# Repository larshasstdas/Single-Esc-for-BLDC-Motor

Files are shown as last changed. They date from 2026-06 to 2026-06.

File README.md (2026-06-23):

# Single ESC for BLDC Motor

A custom single-channel ESC (Electronic Speed Controller) for BLDC motors. I want to programm and test the esc before modifying it into a 4in1 esc i can use for flying a drone.

## Overview

This repository contains the KiCad schematic and PCB layout for a single-channel ESC. The design is based on the DRV8353 gate driver and BSC010N04LSI MOSFETs, controlled by an STM32G431 microcontroller. It includes a buck converter for onboard power regulation, MOSFET-based battery backflow protection, and BEMF sensing for sensorless motor control.

## Files
```
├── KiCad_Files/              # KiCad design source
│   ├── SingleEsc.kicad_pro   # KiCad project file
│   ├── SingleEsc.kicad_sch   # Schematic
│   ├── SingleEsc.kicad_pcb   # PCB layout
│   ├── SingleEsc-job.gbrjob  # Gerber job file
│   ├── SingleEsc-all-pos.csv # Component placement export
│   ├── footprints/           # Custom footprint library
│   ├── myBibs/               # Custom schematic symbol library
│   └── fp-lib-table          # Footprint library table
│
├── Gerber&BOM/               # Manufacturing data
│   ├── GerberESC/            # Gerber and drill files
│   ├── DigiKey_ESC_BOM.csv   # Bill of materials (CSV)
│   ├── DigiKey_ESC_BOM.xlsx  # Bill of materials (Excel)
│   ├── ESC_PickAndPlace.csv  # Pick & place (CSV)
│   └── ESC_PickAndPlace.xlsx # Pick & place (Excel)
│
├── Gerber&BOM.zip            # Zipped Gerber, BOM and Pick & Place files
└── README.md
```
## Bill of Materials

A BOM with all components for buying on Digikey is available in the project files. Some parts need to be bought elsewhere for example the XT60 connector.

## AI Usage

AI was used for helping with a basic idea for a layout, learning about components and an idea of where to buy parts.

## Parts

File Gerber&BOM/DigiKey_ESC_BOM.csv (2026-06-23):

Country of Origin may be different at time of shipment.
The HTSUS and ECCN information shown is for informational purposes only and is not a representation or warranty as to the accuracy or reliability of these classifications. All information is provided "as is" and is subject to change without notice. Any use made of the information provided is without recourse to Digi-Key and at the user's risk.
Index | Manufacturer Part Number | Manufacturer Name | Description | Lead Time | Availability | Stock Status | Attrition % | Requested Quantity 1 | Pack Quantity 1 | Pack Type 1 | Digi-Key Part Number 1 | Unit Price 1 | Extended Price 1 | Minimum Order Quantity 1 | Customer Reference | Requested Part Number | Lead Weeks | Datasheet | Reference Designator | US Import Tariff | Note | Part Status | RoHS Status | REACH Status | Moisture Sensitivity Level (MSL) | ECCN | HTSUS | Country of Origin | Environmental Information | Original Part numbers | Unit of Measure | Image | Product Notes
1 | BSC014N06NSATMA1 | Infineon Technologies | MOSFET N-CH 60V 30A/100A TDSON7 |  | 67.842 | In Stock |  | 10 | 10 | Cut Tape (CT) | BSC014N06NSATMA1CT-ND | 3,10300 | €31.03 | 1 |  | BSC014N06NSATMA1CT-ND | 61 | https://www.infineon.com/dgdl/BSC014N06NS_Rev2.0.pdf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 |  | N/A |  | Active | ROHS3 Compliant | REACH Unaffected | 1 (Unlimited) | EAR99 | 8541.29.0055 | Germany | https://www.cypress.com/file/199231/download | BSC014N06NSATMA1CT-ND | Each | https://mm.digikey.com/Volume0/opasdata/d220001/medias/images/2460/448%3B-P%5EPG-TDSON-8-17%3B-%3B-8-Top-View.jpg
2 | RC0603FR-0710RL | YAGEO | RES 10 OHM 1% 1/10W 0603 |  | 1.195.834 | In Stock |  | 10 | 10 | Cut Tape (CT) | 311-10.0HRCT-ND | 0,03200 | €0.32 | 1 |  | 311-10.0HRCT-ND | 17 | https://yageogroup.com/content/datasheet/asset/file/PYU-RC_GROUP_51_ROHS_L |  | N/A |  | Active | ROHS3 Compliant | REACH Unaffected | 1 (Unlimited) | EAR99 | 8533.21.0030 | Taiwan | https://www.yageogroup.com/content/Resource%20Library/Product%20Environmental%20Compliance/RoHS_Compliance_YAGEO.pdf | 311-10.0HRCT-ND | Each | https://mm.digikey.com/Volume0/opasdata/d220001/derivates/6/003/121/213/cut-tape-render_web%28640x640%29.jpg
3 | RC0603FR-07100RL | YAGEO | RES 100 OHM 1% 1/10W 0603 |  | 1.700.034 | In Stock |  | 10 | 10 | Cut Tape (CT) | 311-100HRCT-ND | 0,02100 | €0.21 | 1 |  | 311-100HRCT-ND | 17 | https://yageogroup.com/content/datasheet/asset/file/PYU-RC_GROUP_51_ROHS_L |  | N/A |  | Active | ROHS3 Compliant | REACH Unaffected | 1 (Unlimited) | EAR99 | 8533.21.0030 | Taiwan | https://www.yageogroup.com/content/Resource%20Library/Product%20Environmental%20Compliance/RoHS_Compliance_YAGEO.pdf | 311-100HRCT-ND | Each | https://mm.digikey.com/Volume0/opasdata/d220001/derivates/6/003/121/213/cut-tape-render_web%28640x640%29.jpg
4 | RC0603FR-071KL | YAGEO | RES 1K OHM 1% 1/10W 0603 |  | 2.422.426 | In Stock |  | 10 | 10 | Cut Tape (CT) | 311-1.00KHRCT-ND | 0,02100 | €0.21 | 1 |  | 311-1.00KHRCT-ND | 17 | https://yageogroup.com/content/datasheet/asset/file/PYU-RC_GROUP_51_ROHS_L |  | N/A |  | Active | ROHS3 Compliant | REACH Unaffected | 1 (Unlimited) | EAR99 | 8533.21.0030 | Taiwan | https://www.yageogroup.com/content/Resource%20Library/Product%20Environmental%20Compliance/RoHS_Compliance_YAGEO.pdf | 311-1.00KHRCT-ND | Each | https://mm.digikey.com/Volume0/opasdata/d220001/derivates/6/003/121/213/cut-tape-render_web%28640x640%29.jpg
5 | RC0603FR-076K8L | YAGEO | RES 6.8K OHM 1% 1/10W 0603 |  | 135.277 | In Stock |  | 10 | 10 | Cut Tape (CT) | 311-6.80KHRCT-ND | 0,02100 | €0.21 | 1 |  | 311-6.80KHRCT-ND | 17 | https://yageogroup.com/content/datasheet/asset/file/PYU-RC_GROUP_51_ROHS_L |  | N/A |  | Active | ROHS3 Compliant | REACH Unaffected | 1 (Unlimited) | EAR99 | 8533.21.0030 | Taiwan | https://www.yageogroup.com/content/Resource%20Library/Product%20Environmental%20Compliance/RoHS_Compliance_YAGEO.pdf | 311-6.80KHRCT-ND | Each | https://mm.digikey.com/Volume0/opasdata/d220001/derivates/6/003/121/213/cut-tape-render_web%28640x640%29.jpg
6 | RC0603FR-0710KL | YAGEO | RES 10K OHM 1% 1/10W 0603 |  | 12.269.132 | In Stock |  | 25 | 25 | Cut Tape (CT) | 311-10.0KHRCT-ND | 0,01600 | €0.40 | 1 |  | 311-10.0KHRCT-ND | 17 | https://yageogroup.com/content/datasheet/asset/file/PYU-RC_GROUP_51_ROHS_L |  | N/A |  | Active | ROHS3 Compliant | REACH Unaffected | 1 (Unlimited) | EAR99 | 8533.21.0030 | Taiwan | https://www.yageogroup.com/content/Resource%20Library/Product%20Environmental%20Compliance/RoHS_Compliance_YAGEO.pdf | 311-10.0KHRCT-ND | Each | https://mm.digikey.com/Volume0/opasdata/d220001/derivates/6/003/121/213/cut-tape-render_web%28640x640%29.jpg
7 | RC0603FR-0739KL | YAGEO | RES 39K OHM 1% 1/10W 0603 |  | 199.716 | In Stock |  | 10 | 10 | Cut Tape (CT) | 311-39.0KHRCT-ND | 0,02100 | €0.21 | 1 |  | 311-39.0KHRCT-ND | 17 | https://yageogroup.com/content/datasheet/asset/file/PYU-RC_GROUP_51_ROHS_L |  | N/A |  | Active | ROHS3 Compliant | REACH Unaffected | 1 (Unlimited) | EAR99 | 8533.21.0030 | Taiwan | https://www.yageogroup.com/content/Resource%20Library/Product%20Environmental%20Compliance/RoHS_Compliance_YAGEO.pdf | 311-39.0KHRCT-ND | Each | https://mm.digikey.com/Volume0/opasdata/d220001/derivates/6/003/121/213/cut-tape-render_web%28640x640%29.jpg
8 | RC0603FR-0743K2L | YAGEO | RES 43.2K OHM 1% 1/10W 0603 |  | 57.553 | In Stock |  | 10 | 10 | Cut Tape (CT) | 311-43.2KHRCT-ND | 0,02100 | €0.21 | 1 |  | 311-43.2KHRCT-ND | 17 | https://yageogroup.com/content/datasheet/asset/file/PYU-RC_GROUP_51_ROHS_L |  | N/A |  | Active | ROHS3 Compliant | REACH Unaffected | 1 (Unlimited) | EAR99 | 8533.21.0030 | Taiwan | https://www.yageogroup.com/content/Resource%20Library/Product%20Environmental%20Compliance/RoHS_Compliance_YAGEO.pdf | 311-43.2KHRCT-ND | Each | https://mm.digikey.com/Volume0/opasdata/d220001/derivates/6/100/962/238/13_0603-%281608-metric%29_web%28640x640%29.jpg
9 | RC0603FR-07100KL | YAGEO | RES 100K OHM 1% 1/10W 0603 |  | 4.896.093 | In Stock |  | 10 | 10 | Cut Tape (CT) | 311-100KHRCT-ND | 0,02100 | €0.21 | 1 |  | 311-100KHRCT-ND | 17 | https://yageogroup.com/content/datasheet/asset/file/PYU-RC_GROUP_51_ROHS_L |  | N/A |  | Active | ROHS3 Compliant | REACH Unaffected | 1 (Unlimited) | EAR99 | 8533.21.0030 | Taiwan | https://www.yageogroup.com/content/Resource%20Library/Product%20Environmental%20Compliance/RoHS_Compliance_YAGEO.pdf | 311-100KHRCT-ND | Each | https://mm.digikey.com/Volume0/opasdata/d220001/derivates/6/003/121/213/cut-tape-render_web%28640x640%29.jpg
10 | STM32G431CBT6 | STMicroelectronics | IC MCU 32BIT 128KB FLASH 48LQFP | 2 expected in stock on 20-Jul-2026 | 0 | Normally Stocking |  | 2 | 2 | Tray | 497-19473-ND | 5,15000 | €10.30 | 1 |  | 497-19473-ND | 30 | https://www.st.com/resource/en/datasheet/stm32g431cb.pdf |  | N/A |  | Active | ROHS3 Compliant | REACH Unaffected | 3 (168 Hours) | 3A991A2 | 8542.31.0025 | Taiwan |  | 497-19473-ND | Each | https://mm.digikey.com/Volume0/opasdata/d220001/medias/images/422/497%7E5B_ME_V2%7ET%7E48.jpg
11 | DRV8353SRTAR | Texas Instruments | DRIVER | 2 expected in stock on 07-Oct-2027 | 0 | Normally Stocking |  | 2 | 2 | Cut Tape (CT) | 296-DRV8353SRTARCT-ND | 4,52000 | €9.04 | 1 |  | 296-DRV8353SRTARCT-ND | 12 | https://www.ti.com/general/docs/suppproductinfo.tsp?distId=10 |  | N/A |  | Active | ROHS3 Compliant | REACH Unaffected | 1 (Unlimited) | EAR99 | 8542.39.0070 | China |  | 296-DRV8353SRTARCT-ND | Each | https://mm.digikey.com/Volume0/opasdata/d220001/medias/images/6222/296%7E4204422%7ERTA%7E40.jpg
12 | LMR33630ADDAR | Texas Instruments | IC REG BUCK ADJ 3A 8SOPWR |  | 3.752 | In Stock |  | 1 | 1 | Cut Tape (CT) | 296-49763-1-ND | 2,45000 | €2.45 | 1 |  | 296-49763-1-ND | 6 | https://www.ti.com/general/docs/suppproductinfo.tsp?distId=10 |  | N/A |  | Active | ROHS3 Compliant | REACH Unaffected | 2 (1 Year) | EAR99 | 8542.39.0070 | Mexico |  | 296-49763-1-ND | Each | https://mm.digikey.com/Volume0/opasdata/d220001/medias/images/6284/296%7E4221637%7EDDA%7E8.jpg
13 | 74437346068 | Würth Elektronik | FIXED IND 6.8UH 3.4A 60 MOHM SMD |  | 4.040 | In Stock |  | 1 | 1 | Cut Tape (CT) | 732-3377-1-ND | 1,93000 | €1.93 | 1 |  | 732-3377-1-ND | 18 | https://www.we-online.com/components/products/datasheet/74437346068.pdf |  | N/A |  | Active | ROHS3 Compliant | REACH Unaffected | 1 (Unlimited) | EAR99 | 8504.50.4000 | China | https://mm.digikey.com/Volume0/opasdata/d220001/medias/docus/744/Certificate_of_Compliance_ROHS.pdf | 732-3377-1-ND | Each | https://mm.digikey.com/Volume0/opasdata/d220001/derivates/6/002/312/WE-LHMI-2_web%28640x640%29.jpg
14 | 61300311121 | Würth Elektronik | CONN HEADER VERT 3POS 2.54MM |  | 254.478 | In Stock |  | 1 | 1 | Bag | 732-5316-ND | 0,11000 | €0.11 | 1 |  | 732-5316-ND | 18 | https://www.we-online.com/components/products/datasheet/61300311121.pdf |  | N/A |  | Active | ROHS3 Compliant | REACH Unaffected | Not Applicable | EAR99 | 8536.69.4040 | Taiwan | https://mm.digikey.com/Volume0/opasdata/d220001/medias/docus/744/Certificate_of_Compliance_ROHS.pdf | 732-5316-ND | Each | https://mm.digikey.com/Volume0/opasdata/d220001/medias/images/1006/61300311121.JPG
15 | FTSH-105-01-L-DV | Samtec Inc. | CONN HEADER SMD 10POS 1.27MM | Unable to be ordered | 2.661 | In Stock - Non-Stock |  | 1 | 1 | Bulk | SAM1161-05-ND | 1,38000 | €1.38 | 1 |  | SAM1161-05-ND | 2 | https://suddendocs.samtec.com/catalog_english/ftsh_smt.pdf |  | N/A |  | Discontinued at Digi-Key | ROHS3 Compliant | REACH Unaffected | 1 (Unlimited) | EAR99 | 8536.69.4040 | United States |  | SAM1161-05-ND | Each | https://mm.digikey.com/Volume0/opasdata/d220001/medias/images/2514/FTSH-1xx-0x-x-DV.jpg
16 | TLR3APSDTE3L00F50 | KOA Speer Electronics, Inc. | RES 3M OHM 1% 5W 2512 |  | 1.387 | In Stock |  | 4 | 4 | Cut Tape (CT) | 2019-TLR3APSDTE3L00F50CT-ND | 1,32000 | €5.28 | 1 |  | 2019-TLR3APSDTE3L00F50CT-ND | 10 | https://www.koaspeer.com/pdfs/TLR-2BW-2BP-2HW-3AP-3APS.pdf |  | N/A |  | Active | ROHS3 Compliant | REACH Unaffected | 1 (Unlimited) | EAR99 | 8533.21.0030 | Japan | https://www.koaglobal.com/product/common/rohs|https://mm.digikey.com/Volume0/opasdata/d220001/medias/docus/5718/2019_KOA%20Speer%20RoHS3%20Statement.pdf | 2019-TLR3APSDTE3L00F50CT-ND | Each | https://mm.digikey.com/Volume0/opasdata/d220001/medias/images/320/2019%3B%3BTLR-2512%286432%29-3mOhm.JPG
17 | C0603C102K5RACTU | KEMET | CAP CER 1000PF 50V X7R 0603 |  | 2.155.016 | In Stock |  | 10 | 10 | Cut Tape (CT) | 399-C0603C102K5RACTUCT-ND | 0,03600 | €0.36 | 1 |  | 399-C0603C102K5RACTUCT-ND | 22 | https://yageogroup.com/content/datasheet/asset/file/KEM_C1002_X7R_SMD |  | N/A |  | Active | ROHS3 Compliant | REACH Unaffected | 1 (Unlimited) | EAR99 | 8532.24.0020 | Taiwan |  | 399-C0603C102K5RACTUCT-ND | Each | https://mm.digikey.com/Volume0/opasdata/d220001/derivates/6/003/121/213/cut-tape-render_web%28640x640%29.jpg
18 | C0603C103K5RACTU | KEMET | CAP CER 10000PF 50V X7R 0603 |  | 5.541.875 | In Stock |  | 10 | 10 | Cut Tape (CT) | 399-C0603C103K5RACTUCT-ND | 0,04100 | €0.41 | 1 |  | 399-C0603C103K5RACTUCT-ND | 22 | https://yageogroup.com/content/datasheet/asset/file/KEM_C1002_X7R_SMD |  | N/A |  | Active | ROHS3 Compliant | REACH Unaffected | 1 (Unlimited) | EAR99 | 8532.24.0020 | Taiwan |  | 399-C0603C103K5RACTUCT-ND | Each | https://mm.digikey.com/Volume0/opasdata/d220001/derivates/6/003/121/213/cut-tape-render_web%28640x640%29.jpg
19 | C0603C473K5RACTU | KEMET | CAP CER 0.047UF 50V X7R 0603 |  | 494.126 | In Stock |  | 10 | 10 | Cut Tape (CT) | 399-C0603C473K5RACTUCT-ND | 0,04000 | €0.40 | 1 |  | 399-C0603C473K5RACTUCT-ND | 12 | https://yageogroup.com/content/datasheet/asset/file/KEM_C1002_X7R_SMD |  | N/A |  | Active | ROHS3 Compliant | REACH Unaffected | 1 (Unlimited) | EAR99 | 8532.24.0020 | China |  | 399-C0603C473K5RACTUCT-ND | Each | https://mm.digikey.com/Volume0/opasdata/d220001/derivates/6/003/121/213/cut-tape-render_web%28640x640%29.jpg
20 | C0603C104K5RACTU | KEMET | CAP CER 0.1UF 50V X7R 0603 |  | 8.437.259 | In Stock |  | 10 | 10 | Cut Tape (CT) | 399-C0603C104K5RACTUCT-ND | 0,04700 | €0.47 | 1 |  | 399-C0603C104K5RACTUCT-ND | 12 | https://yageogroup.com/content/datasheet/asset/file/KEM_C1002_X7R_SMD |  | N/A |  | Active | ROHS3 Compliant | REACH Unaffected | 1 (Unlimited) | EAR99 | 8532.24.0020 | China |  | 399-C0603C104K5RACTUCT-ND | Each | https://mm.digikey.com/Volume0/opasdata/d220001/derivates/6/003/121/213/cut-tape-render_web%28640x640%29.jpg
21 | CC0603KRX7R9BB224 | YAGEO | CAP CER 0.22UF 50V X7R 0603 |  | 2.684 | In Stock |  | 10 | 10 | Cut Tape (CT) | 311-3374-1-ND | 0,13700 | €1.37 | 1 |  | 311-3374-1-ND | 20 | https://yageogroup.com/content/datasheet/asset/file/UPY-GPHC_X7R_6_3V-TO-250V |  | N/A |  | Active | ROHS3 Compliant | REACH Unaffected | 1 (Unlimited) | EAR99 | 8532.24.0020 | Taiwan |  | 311-3374-1-ND | Each | https://mm.digikey.com/Volume0/opasdata/d220001/medias/images/2488/0603%289mmthickness%29.jpg
22 | C0603C105K4RACTU | KEMET | CAP CER 1UF 16V X7R 0603 |  | 4.644.752 | In Stock |  | 10 | 10 | Cut Tape (CT) | 399-C0603C105K4RACTUCT-ND | 0,04600 | €0.46 | 1 |  | 399-C0603C105K4RACTUCT-ND | 38 | https://yageogroup.com/content/datasheet/asset/file/KEM_C1002_X7R_SMD |  | N/A |  | Active | ROHS3 Compliant | REACH Unaffected | 1 (Unlimited) | EAR99 | 8532.24.0020 | Taiwan |  | 399-C0603C105K4RACTUCT-ND | Each | https://mm.digikey.com/Volume0/opasdata/d220001/derivates/6/003/121/213/cut-tape-render_web%28640x640%29.jpg
23 | GCM188R71E105KA64J | Murata Electronics | CAP CER 1UF 25V X7R 0603 |  | 142.747 | In Stock |  | 10 | 10 | Cut Tape (CT) | 490-GCM188R71E105KA64JCT-ND | 0,08500 | €0.85 | 1 |  | 490-GCM188R71E105KA64JCT-ND | 21 | https://search.murata.co.jp/Ceramy/image/img/A01X/G101/ENG/GCM188R71E105KA64-04A.pdf |  | N/A |  | Active | ROHS3 Compliant | REACH Unaffected | 1 (Unlimited) | EAR99 | 8532.24.0020 | Philippines |  | 490-GCM188R71E105KA64JCT-ND | Each | https://mm.digikey.com/Volume0/opasdata/d220001/medias/images/5447/490-Ceramic-Capacitor-Tan-Field.jpg
24 | GCM31CR71E475KA55L | Murata Electronics | CAP CER 4.7UF 25V X7R 1206 |  | 210.874 | In Stock |  | 2 | 2 | Cut Tape (CT) | 490-4794-1-ND | 0,27000 | €0.54 | 1 |  | 490-4794-1-ND | 21 | https://search.murata.co.jp/Ceramy/image/img/A01X/G101/ENG/GCM31CR71E475KA55-01A.pdf |  | N/A |  | Active | ROHS3 Compliant | REACH Unaffected | 1 (Unlimited) | EAR99 | 8532.24.0020 | Philippines |  | 490-4794-1-ND | Each | https://mm.digikey.com/Volume0/opasdata/d220001/medias/images/5447/490-Ceramic-Capacitor-Tan-Field.jpg
25 | C3225X7R1E106K250AC | TDK | CAP CER 10UF 25V X7R 1210 |  | 107.110 | In Stock |  | 2 | 2 | Cut Tape (CT) | 445-3942-1-ND | 0,52000 | €1.04 | 1 |  | 445-3942-1-ND | 12 | https://product.tdk.com/system/files/dam/doc/product/capacitor/ceramic/mlcc/catalog/mlcc_commercial_general_en.pdf |  | N/A |  | Active | ROHS3 Compliant | REACH Unaffected | 1 (Unlimited) | EAR99 | 8532.24.0020 | Japan | https://product.tdk.com/system/files/dam/doc/product/capacitor/ceramic/mlcc/rohs/mlccrohs_commercial_general_en.pdf|https://product.tdk.com/en/environment/index.html | 445-3942-1-ND | Each | https://mm.digikey.com/Volume0/opasdata/d220001/medias/images/4848/445_1210-%283225-Metric%29-2%2C80mm-C-Series.jpg
26 | C3225X7R1H106K250AC | TDK | COMMERCIAL GRADE GENERAL PURPOSE |  | 63.842 | In Stock |  | 2 | 2 | Cut Tape (CT) | 445-C3225X7R1H106K250ACCT-ND | 0,83000 | €1.66 | 1 |  | 445-C3225X7R1H106K250ACCT-ND | 12 | https://product.tdk.com/system/files/dam/doc/product/capacitor/ceramic/mlcc/catalog/mlcc_commercial_general_en.pdf |  | N/A |  | Active | ROHS3 Compliant | REACH Unaffected | 1 (Unlimited) | EAR99 | 8532.24.0020 | Japan | https://product.tdk.com/system/files/dam/doc/product/capacitor/ceramic/mlcc/rohs/mlccrohs_commercial_general_en.pdf|https://product.tdk.com/en/environment/index.html | 445-C3225X7R1H106K250ACCT-ND | Each | https://mm.digikey.com/Volume0/opasdata/d220001/medias/images/4848/445_1210-%283225-Metric%29-2%2C80mm-C-Series.jpg
27 | C3225X7R1C226K250AC | TDK | CAP CER 22UF 16V X7R 1210 |  | 162.288 | In Stock |  | 5 | 5 | Cut Tape (CT) | 445-3945-1-ND | 0,65000 | €3.25 | 1 |  | 445-3945-1-ND | 24 | https://product.tdk.com/system/files/dam/doc/product/capacitor/ceramic/mlcc/catalog/mlcc_commercial_general_en.pdf |  | N/A |  | Not For New Designs | ROHS3 Compliant | REACH Unaffected | 1 (Unlimited) | EAR99 | 8532.24.0020 | Japan | https://product.tdk.com/system/files/dam/doc/product/capacitor/ceramic/mlcc/rohs/mlccrohs_commercial_general_en.pdf|https://product.tdk.com/en/environment/index.html | 445-3945-1-ND | Each | https://mm.digikey.com/Volume0/opasdata/d220001/medias/images/4848/445_1210-%283225-Metric%29-2%2C80mm-C-Series.jpg
28 | GYG1V471MCW1GS | Nichicon | 35V 470F HYBRID POLYMER CHIP CHI |  | 875 | In Stock |  | 3 | 3 | Cut Tape (CT) | 493-GYG1V471MCW1GSCT-ND | 2,01000 | €6.03 | 1 |  | 493-GYG1V471MCW1GSCT-ND | 25 | https://www.nichicon.com/getmedia/794506d5-b0a7-4431-90fa-9a3c61397cd1/e-gyg_1.pdf |  | N/A |  | Active | ROHS3 Compliant | REACH Unaffected | 1 (Unlimited) | EAR99 | 8532.22.0020 | Japan |  | 493-GYG1V471MCW1GSCT-ND | Each | https://mm.digikey.com/Volume0/opasdata/d220001/derivates/6/003/235/317/MFG_2610_20SERIES_web%28640x640%29.jpg
29 | SZMMSZ5245BT1G | onsemi | DIODE ZENER 15V 500MW SOD123 |  | 2.927 | In Stock |  | 2 | 2 | Cut Tape (CT) | SZMMSZ5245BT1GOSCT-ND | 0,29000 | €0.58 | 1 |  | SZMMSZ5245BT1GOSCT-ND | 45 | https://www.onsemi.com/pdf/datasheet/mmsz5221bt1-d.pdf |  | N/A |  | Active | ROHS3 Compliant | REACH Unaffected | 1 (Unlimited) | EAR99 | 8541.10.0050 | China | https://www.onsemi.com/site/pdf/RoHS-statement.pdf|https://www.onsemi.com/site/pdf/onsemi-REACH-Statement.pdf|https://www.onsemi.com/PowerSolutions/MaterialComposition.do?export=pdf&opnId=SZMMSZ5245BT1G | SZMMSZ5245BT1GOSCT-ND | Each | https://mm.digikey.com/Volume0/opasdata/d220001/medias/images/6241/488%7E425-04%7EZ%7E2.jpg
30 | BAT54W | Diotec Semiconductor | DIODE SCHOTTKY 30V 200MA SOT323 | 2 estimated in stock on 09-Oct-2026 | 0 | Normally Stocking |  | 2 | 2 | Cut Tape (CT) | 4878-BAT54WCT-ND | 0,16000 | €0.32 | 1 |  | 4878-BAT54WCT-ND | 10 | https://diotec.com/request/datasheet/bat54w.pdf |  | N/A |  | Active | ROHS3 Compliant | REACH Unaffected | 1 (Unlimited) | EAR99 | 8541.10.0070 | China | https://diotec.com/request/imds/p201_e.pdf | 4878-BAT54WCT-ND | Each | https://mm.digikey.com/Volume0/opasdata/d220001/derivates/6/003/224/678/4878%7ESOT323%7E%7E3_web%28640x640%29.jpg

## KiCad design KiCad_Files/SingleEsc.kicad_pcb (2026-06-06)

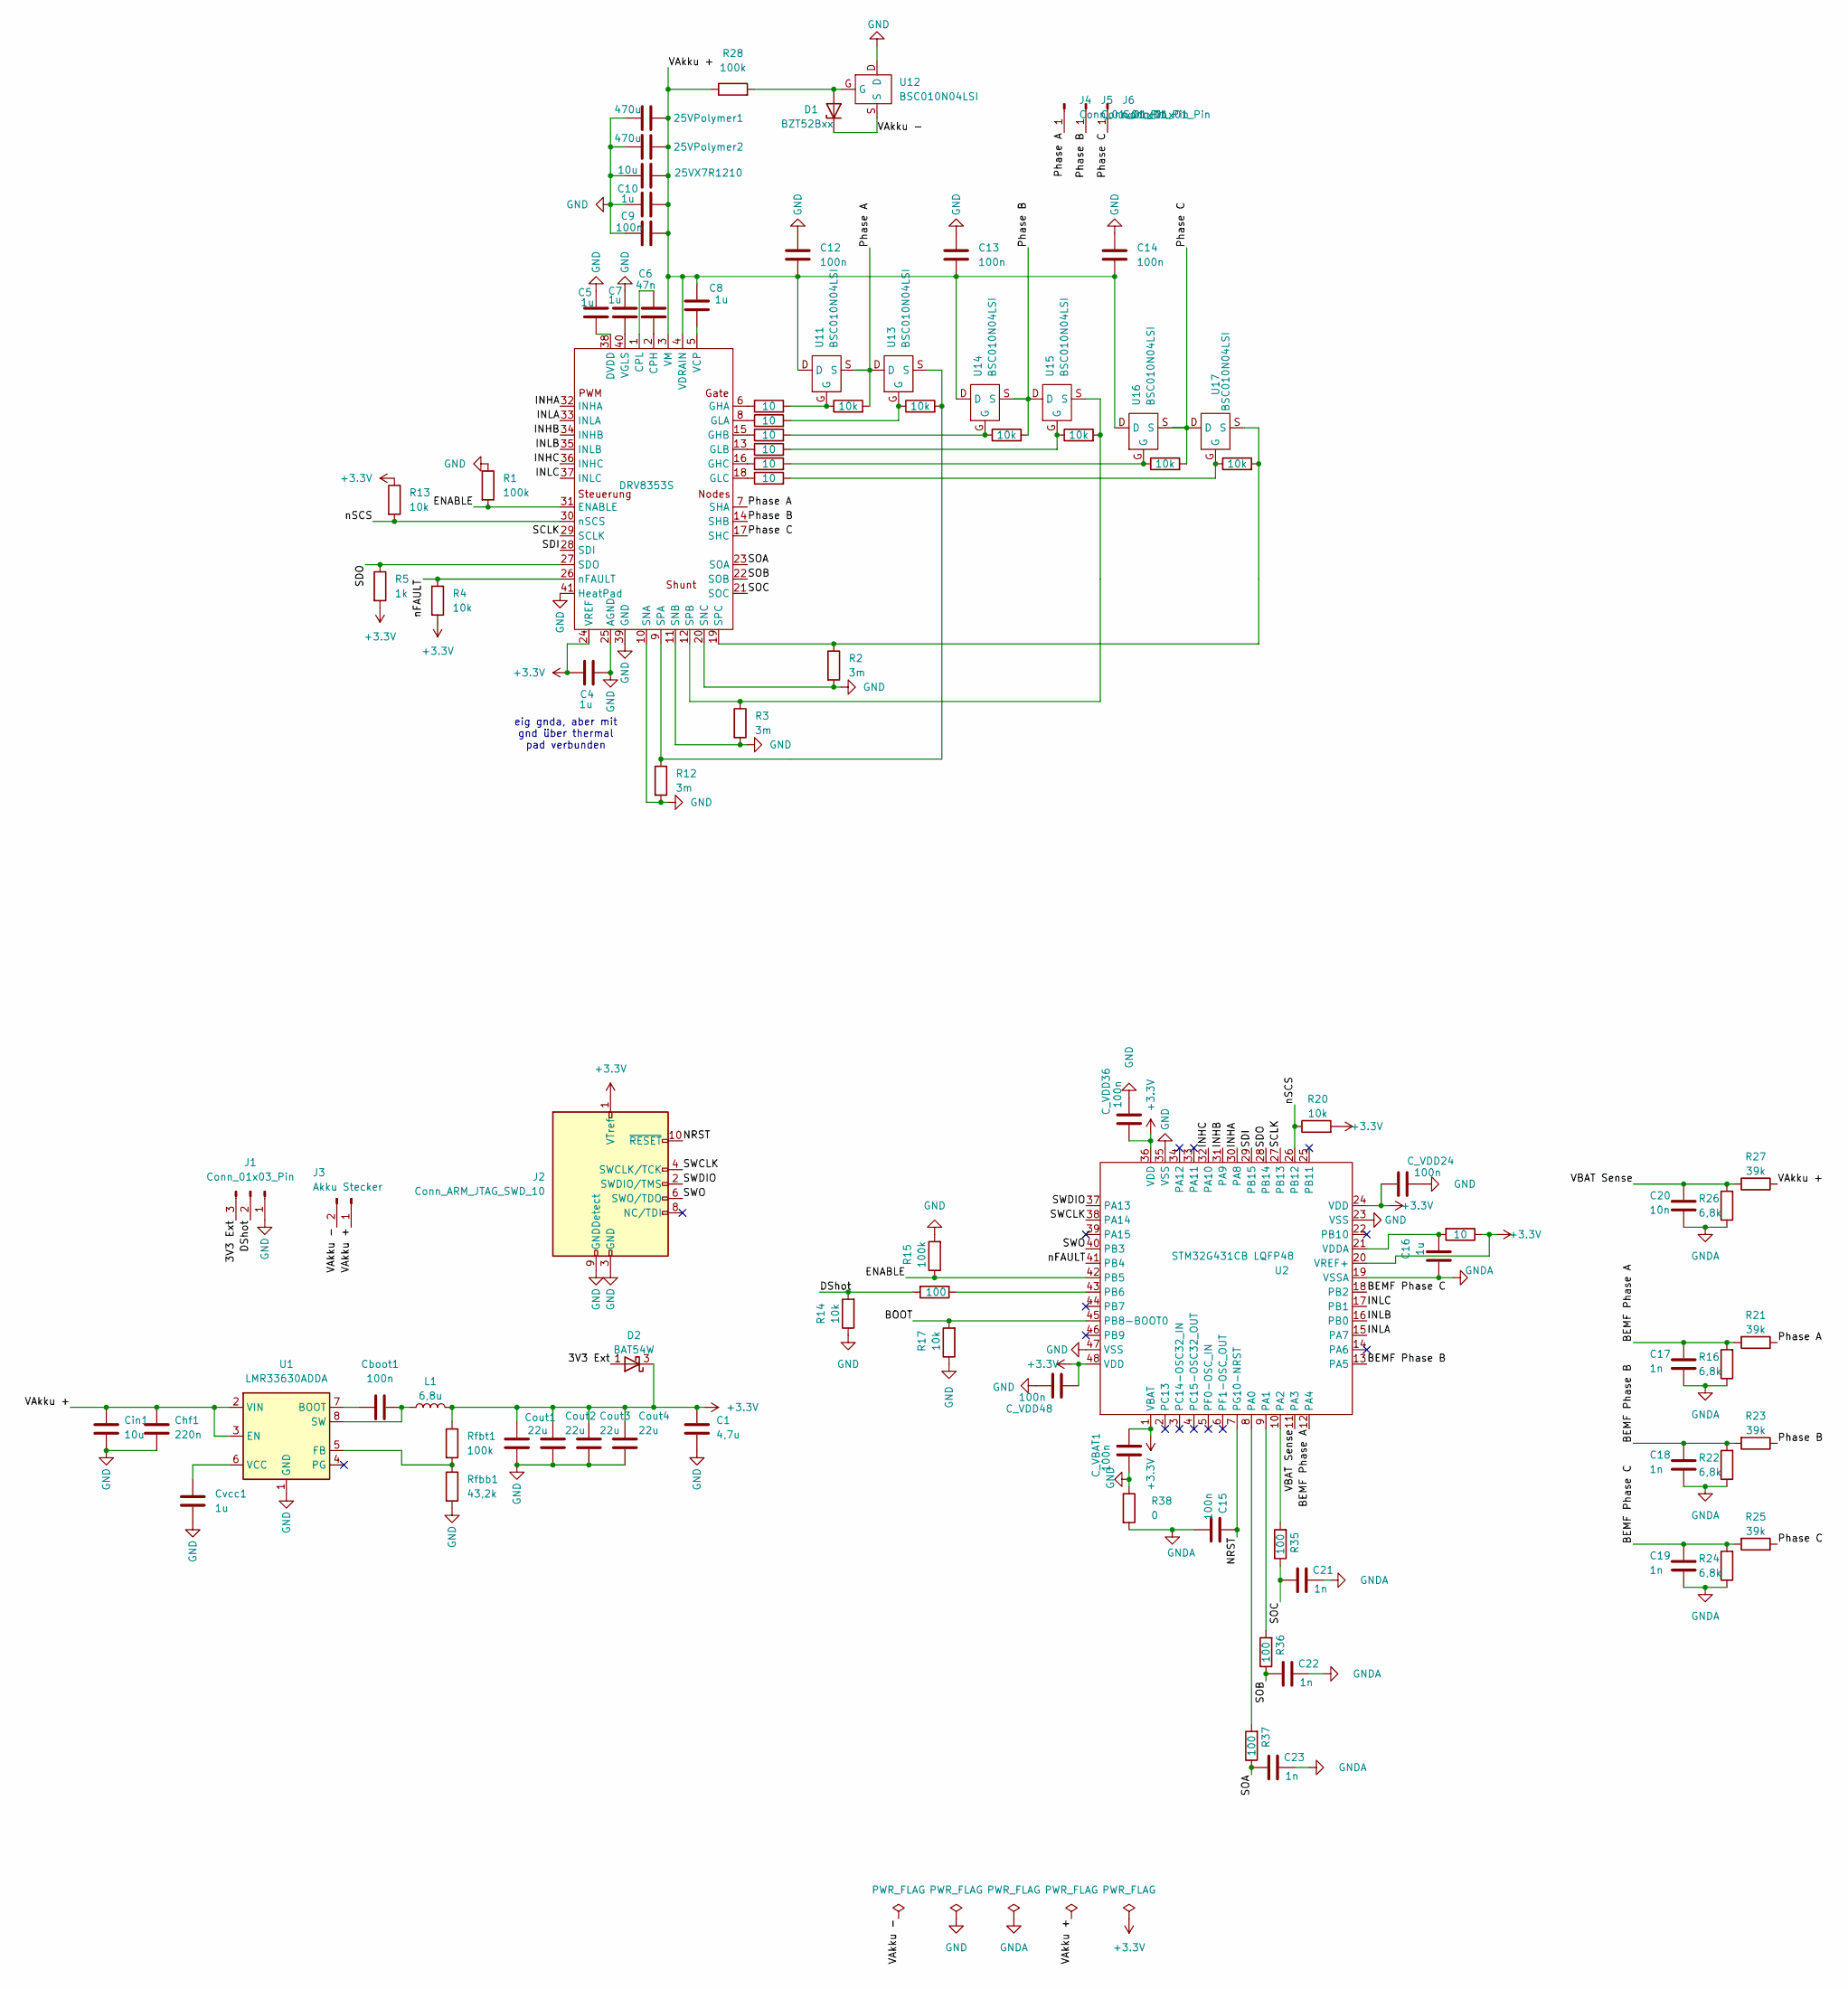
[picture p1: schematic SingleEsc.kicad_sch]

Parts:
25VPolymer1, 25VPolymer2: 470u; C_1206_3216Metric
25VX7R1210: 10u; C_0603_1608Metric
C1: 4,7u; C_0603_1608Metric
C4, C5, C7, C8, C10, C16: 1u; C_0603_1608Metric
C6: 47n; C_0603_1608Metric
C9, C15: 100n; C_0603_1608Metric
C12, C13, C14: 100n; C_0805_2012Metric
C17, C18, C19, C21, C22, C23: 1n; C_0603_1608Metric
C20: 10n; C_0603_1608Metric
C_VBAT1: 100n; C_0603_1608Metric
C_VDD24, C_VDD36, C_VDD48: 100n; C_0603_1608Metric
Cboot1: 100n; C_0603_1608Metric
Chf1: 220n; C_0603_1608Metric
Cin1: 10u; C_1210_3225Metric
Cout1, Cout2, Cout3, Cout4: 22u; C_1210_3225Metric
Cvcc1: 1u; C_0603_1608Metric
D1: BZT52Bxx; D_SOD-123F
D2: BAT54W; SOT-323_SC-70
J1: Conn_01x03_Pin; PinHeader_1x03_P2.54mm_Horizontal
J2: Conn_ARM_JTAG_SWD_10; PinHeader_2x05_P1.27mm_Vertical_SMD
J3: Akku Stecker; AMASS_XT60PW-M_1x02_P7.20mm_Horizontal
J4, J5, J6: Conn_01x01_Pin; SolderWirePad_1x01_SMD_5x10mm
L1: 6,8u; L_Wurth_WE-LHMI-7030
R1: 100k; C_0603_1608Metric
R2, R3, R12: 3m; R_2512_6332Metric
R4, R13: 10k; C_0603_1608Metric
R5: 1k; C_0603_1608Metric
R6, R7, R8, R9, R10, R11, R18: 10; R_0805_2012Metric
R14, R17, R20, R29, R30, R31, R32, R33, R34: 10k; R_0603_1608Metric
R15, R28: 100k; R_0603_1608Metric
R16, R22, R24, R26: 6,8k; R_0603_1608Metric
R19, R35, R36, R37: 100; R_0603_1608Metric
R21, R23, R25, R27: 39k; R_0603_1608Metric
R38: 0; R_0603_1608Metric
Rfbb1: 43,2k; C_0603_1608Metric
Rfbt1: 100k; C_0603_1608Metric
U1: LMR33630ADDA; Texas_HSOP-8-1EP_3.9x4.9mm_P1.27mm_ThermalVias
U2: STM32G431CB LQFP48
U11, U12, U13, U14, U15, U16, U17: BSC010N04LSI
U18: DRV8353S

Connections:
+3.3V: C1.1, C4.1, C_VBAT1.1, C_VDD24.1, C_VDD36.1, C_VDD48.1, Cout1.1, Cout2.1, Cout3.1, Cout4.1, D2.3 (K), J2.1 (VTref), L1.1, R4.2, R5.2, R13.1, R18.1, R20.2, Rfbt1.1, U2.1 (VBAT), U2.20 (VREF+), U2.24 (VDD), U2.36 (VDD), U2.48 (VDD), U18.24 (VREF)
/3V3 Ext: D2.1 (A), J1.3
/BEMF Phase A: C17.1, R16.2, R21.2, U2.12 (PA4)
/BEMF Phase B: C18.1, R22.2, R23.2, U2.13 (PA5)
/BEMF Phase C: C19.1, R24.2, R25.2, U2.18 (PB2)
/BOOT: R17.2, U2.45 (PB8-BOOT0)
/DShot: J1.2, R14.2, R19.2
/ENABLE: R1.2, R15.1, U2.42 (PB5), U18.31 (ENABLE)
/INHA: U2.30 (PA8), U18.32 (INHA)
/INHB: U2.31 (PA9), U18.34 (INHB)
/INHC: U2.32 (PA10), U18.36 (INHC)
/INLA: U2.15 (PA7), U18.33 (INLA)
/INLB: U2.16 (PB0), U18.35 (INLB)
/INLC: U2.17 (PB1), U18.37 (INLC)
/NRST: C15.1, J2.10 (~RESET), U2.7 (PG10-NRST)
/Phase A: J4.1 (Pin_1_1), R21.1, R29.2, U11.S, U13.D, U18.7 (SHA)
/Phase B: J5.1 (Pin_1_1), R23.1, R31.2, U14.S, U15.D, U18.14 (SHB)
/Phase C: J6.1 (Pin_1_1), R25.1, R33.2, U16.S, U17.D, U18.17 (SHC)
/SCLK: U2.27 (PB13), U18.29 (SCLK)
/SDI: U2.29 (PB15), U18.28 (SDI)
/SDO: R5.1, U2.28 (PB14), U18.27 (SDO)
/SOA: C23.2, R37.1, U18.23 (SOA)
/SOB: C22.2, R36.1, U18.22 (SOB)
/SOC: C21.2, R35.1, U18.21 (SOC)
/SWCLK: J2.4 (SWCLK/TCK), U2.38 (PA14)
/SWDIO: J2.2 (SWDIO/TMS), U2.37 (PA13)
/SWO: J2.6 (SWO/TDO), U2.40 (PB3)
/VAkku +: 25VPolymer1.2, 25VPolymer2.2, 25VX7R1210.2, C8.1, C9.2, C10.2, C12.1, C13.1, C14.1, Chf1.1, Cin1.1, J3.1, R27.1, R28.1, U1.2 (VIN), U1.3 (EN), U11.D, U14.D, U16.D, U18.3 (VM), U18.4 (VDRAIN)
/VAkku -: D1.1 (K), J3.2, U12.S
/VBAT Sense: C20.1, R26.2, R27.2, U2.11 (PA3)
/nFAULT: R4.1, U2.41 (PB4), U18.26 (nFAULT)
/nSCS: R13.2, R20.1, U2.26 (PB12), U18.30 (nSCS)
GND: 25VPolymer1.1, 25VPolymer2.1, 25VX7R1210.1, C1.2, C4.2, C5.1, C7.1, C9.1, C10.1, C12.2, C13.2, C14.2, C_VBAT1.2, C_VDD24.2, C_VDD36.2, C_VDD48.2, Chf1.2, Cin1.2, Cout1.2, Cout2.2, Cout3.2, Cout4.2, Cvcc1.2, J1.1, J2.3 (GND), J2.5 (GND), J2.9 (GNDDetect), R1.1, R2.2, R3.2, R12.2, R14.1, R15.2, R17.1, R38.1, Rfbb1.2, U1.1 (GND), U1.9 (GND), U2.23 (VSS), U2.35 (VSS), U2.47 (VSS), U12.D, U18.10 (SNA), U18.11 (SNB), U18.20 (SNC), U18.25 (AGND), U18.39 (GND), U18.41 (HeatPad)
GNDA: C15.2, C16.1, C17.2, C18.2, C19.2, C20.2, C21.1, C22.1, C23.1, R16.1, R22.1, R24.1, R26.1, R38.2, U2.19 (VSSA)
unnamed: D1.2 (A), R28.2, U12.G
unnamed: R10.2, R33.1, U16.G
unnamed: R11.2, R34.1, U17.G
unnamed: R6.2, R29.1, U11.G
unnamed: R7.2, R30.1, U13.G
unnamed: R8.2, R31.1, U14.G
unnamed: R9.2, R32.1, U15.G
unnamed: Cboot1.1, U1.7 (BOOT)
unnamed: Rfbb1.1, Rfbt1.2, U1.5 (FB)
unnamed: Cboot1.2, L1.2, U1.8 (SW)
unnamed: Cvcc1.1, U1.6 (VCC)
unnamed: R37.2, U2.8 (PA0)
unnamed: R36.2, U2.9 (PA1)
unnamed: R35.2, U2.10 (PA2)
unnamed: R19.1, U2.43 (PB6)
unnamed: C16.2, R18.2, U2.21 (VDDA)
unnamed: C6.2, U18.2 (CPH)
unnamed: C6.1, U18.1 (CPL)
unnamed: C5.2, U18.38 (DVDD)
unnamed: R6.1, U18.6 (GHA)
unnamed: R8.1, U18.15 (GHB)
unnamed: R10.1, U18.16 (GHC)
unnamed: R7.1, U18.8 (GLA)
unnamed: R9.1, U18.13 (GLB)
unnamed: R11.1, U18.18 (GLC)
unnamed: R12.1, R30.2, U13.S, U18.9 (SPA)
unnamed: R3.1, R32.2, U15.S, U18.12 (SPB)
unnamed: R2.1, R34.2, U17.S, U18.19 (SPC)
unnamed: C8.2, U18.5 (VCP)
unnamed: C7.2, U18.40 (VGLS)

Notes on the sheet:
eig gnda, aber mit gnd über thermal pad verbunden

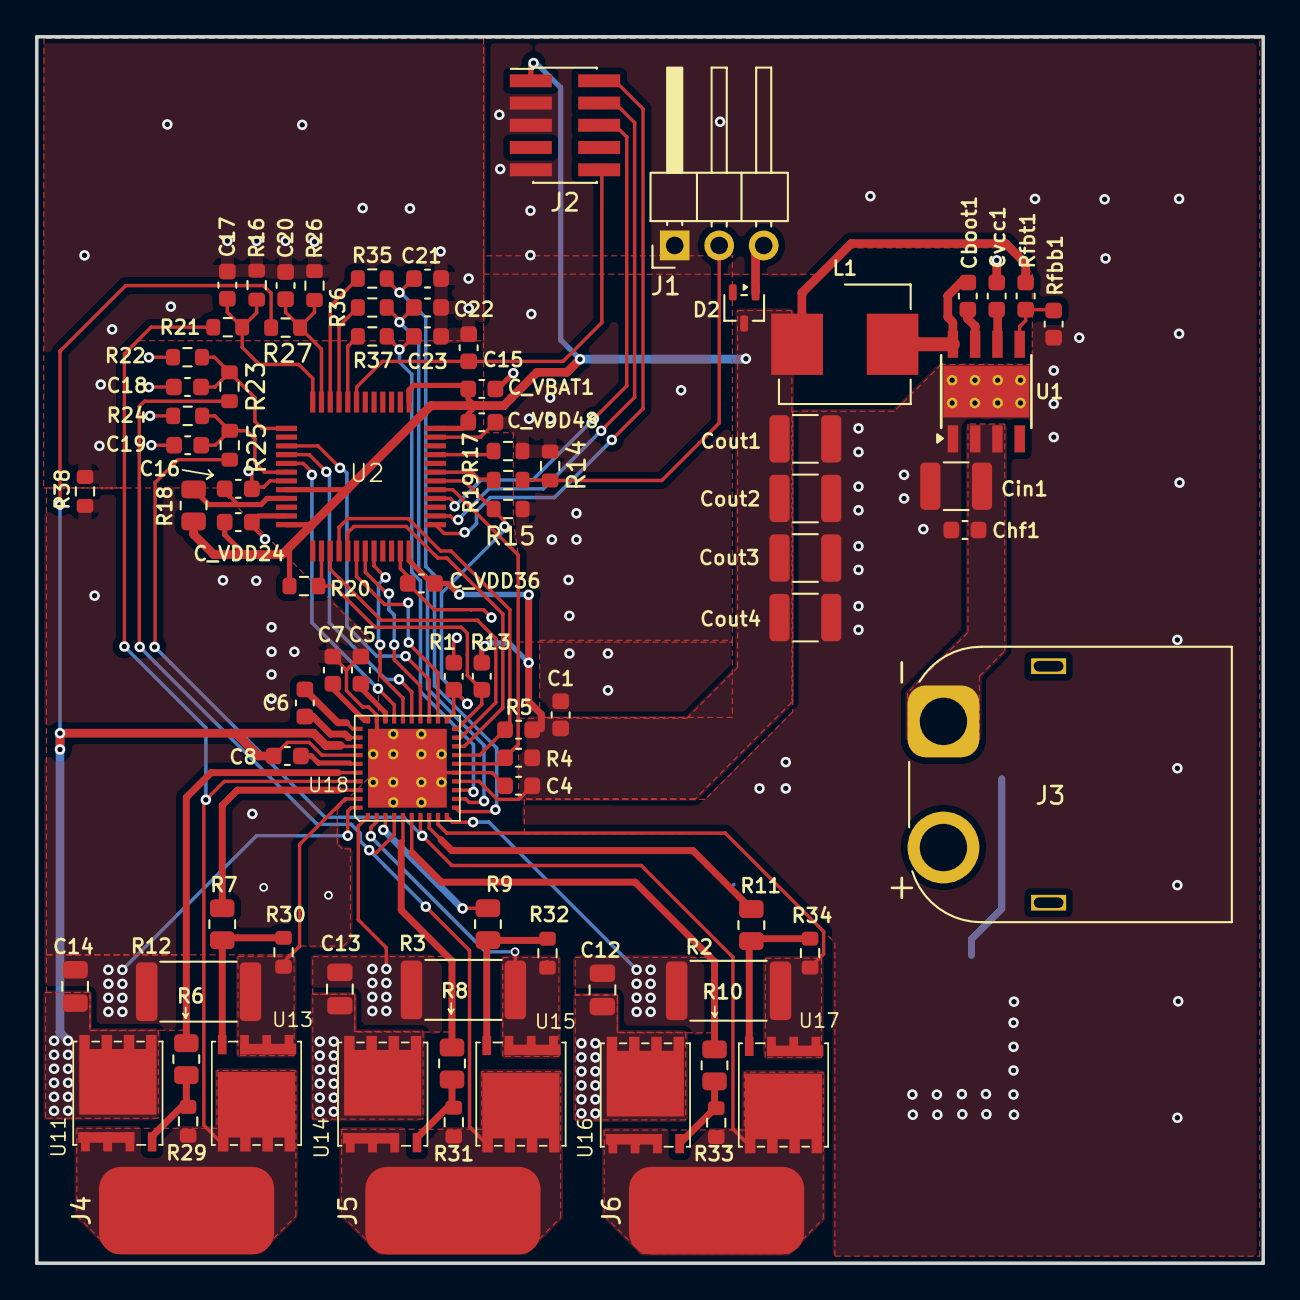
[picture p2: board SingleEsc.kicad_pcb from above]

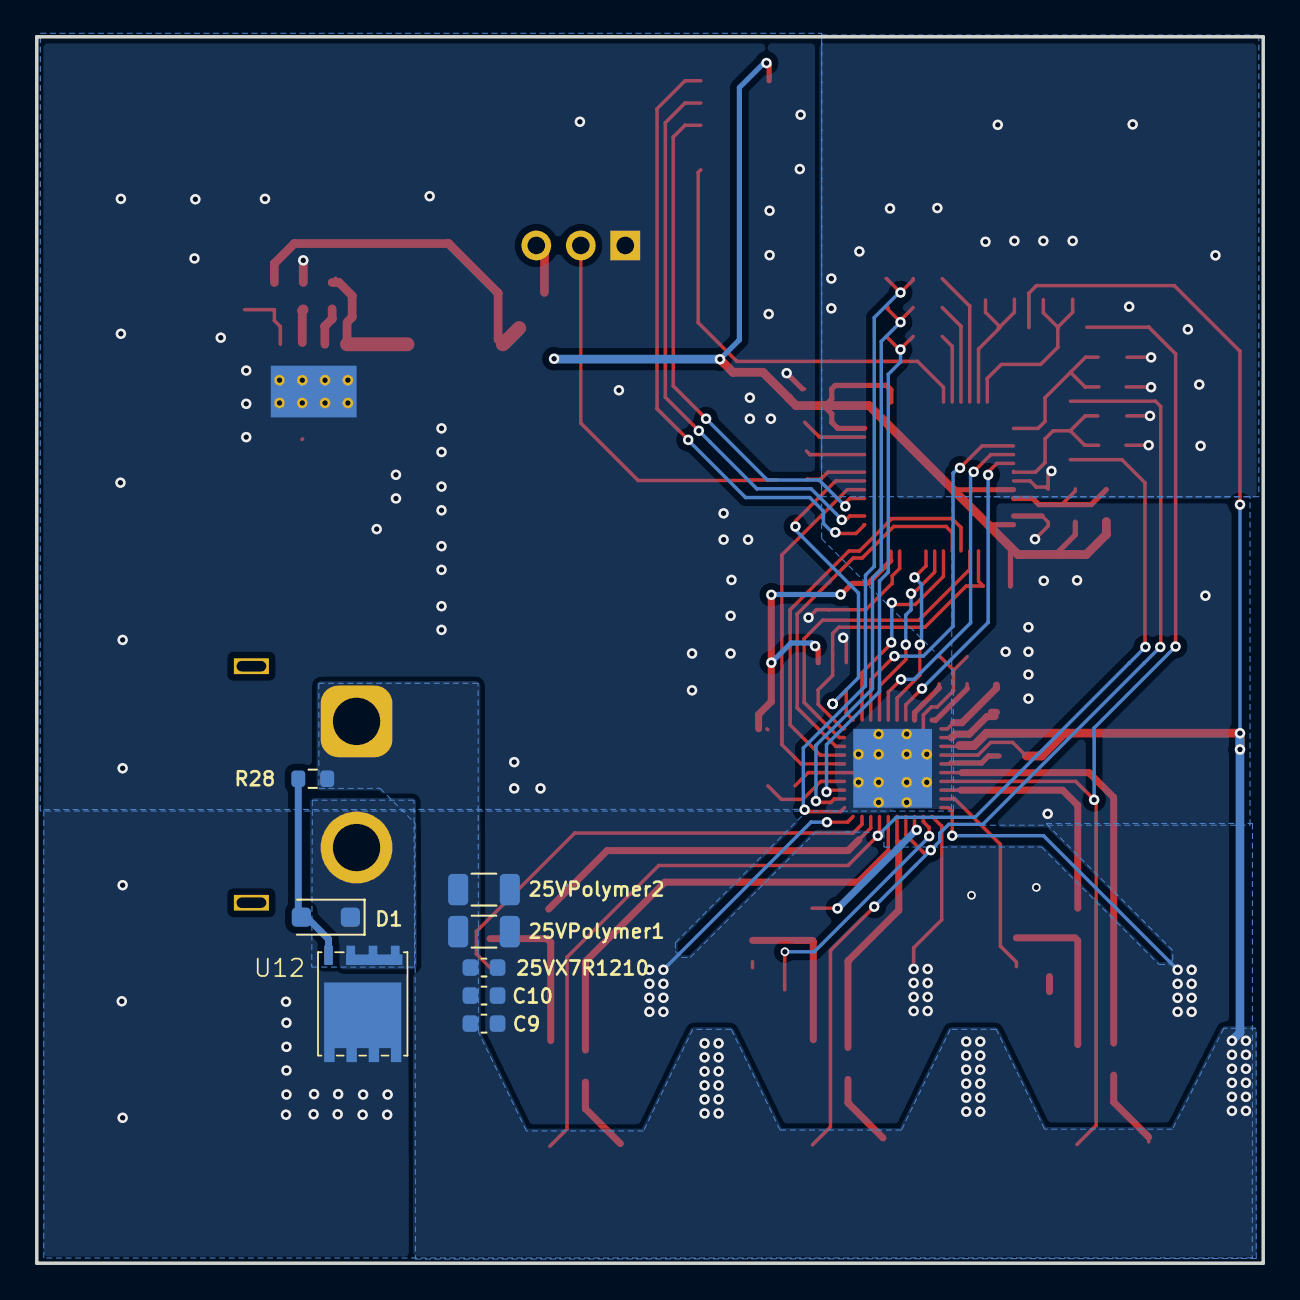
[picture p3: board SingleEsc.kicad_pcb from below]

Board: 2 copper layers, 70.0 x 70.0 mm, 94 parts (8 on the bottom side), 64 nets.

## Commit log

2026-06-06 Single Esc Pcb Layout
    [SingleEsc-B_Cu.gbl, SingleEsc-B_Mask.gbs, SingleEsc-B_Paste.gbp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]
2026-06-06 added BOM
    [ESC_Stueckliste.xlsx]
2026-06-06 renamed BOM
    [ESC_BOM.xlsx]
2026-06-13 updated BOM
    [DigiKey_ESC_BOM.xlsx, ESC_BOM.xlsx]
2026-06-23 sorted repo and added PichAndPlace
    [DigiKey_ESC_BOM.csv, DigiKey_ESC_BOM.xlsx, ESC_PickAndPlace.csv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]
